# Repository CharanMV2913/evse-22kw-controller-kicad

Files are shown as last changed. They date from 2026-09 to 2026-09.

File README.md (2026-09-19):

# 22 kW EVSE controller project

The repository now contains the prototype implementation specification, safety-state-machine guidance, release checklist, and initial KiCad board outline.

This is an engineering prototype baseline, not a certified charger. The next mandatory step is exact component selection and schematic capture against the chosen external Type A + RDC-DD or Type B protection assembly. The board must remain SELV/control-only; do not add 415 V conductors to it.

See `docs/implementation-spec.md` and `docs/release-checklist.md` before ordering boards.

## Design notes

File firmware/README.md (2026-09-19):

# Prototype safety firmware skeleton

This folder contains only a safe-state reference skeleton. It does not control a certified EVSE by itself and must not be used as the sole contactor safety mechanism.

The firmware must default `CONTACTOR_REQUEST` low, require all local safety inputs healthy, and latch faults. The external normally-closed safety chain must interrupt the contactor coil independently of the ESP32-S3.

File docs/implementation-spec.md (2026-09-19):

# Prototype implementation specification

This document is the release baseline for schematic capture and assembly of the control PCB. It intentionally excludes the hazardous 415 V power path.

## Functional sections

### A. 24 V SELV input

`J1-1 = +24V_SELv`, `J1-2 = 0V_SELv`. Provide an input fuse/PTC, reverse-polarity protection, TVS, and buck/LDO rails for 12 V and 3.3 V. The selected supply must be certified and current-limited.

### B. ESP32-S3

Use an ESP32-S3-WROOM-1 module with the manufacturer's recommended decoupling, boot strapping, USB/UART programming interface, antenna keepout, and exposed-ground requirements. Do not route copper or place metal under the antenna keepout.

### C. Hardware safety interlock

The external safety chain provides an isolated `SAFETY_OK` status and independently interrupts the external contactor coil circuit. The PCB's `CONTACTOR_REQUEST` is only an enable request. The request path must default low during reset and be ANDed with a hardware watchdog/fault signal before reaching the external relay interface.

Inputs are active-low normally-closed safety contacts unless the selected certified module specifies otherwise:

- emergency stop
- RCD/RDC-DD trip
- PE monitor healthy
- phase/voltage monitor healthy
- thermal monitor healthy
- enclosure/door interlock

### D. Control Pilot / Proximity Pilot

Use a dedicated IEC 61851-compatible CP front end or a verified reference circuit. CP must provide state measurement, diode check, pilot duty-cycle measurement, and protected ±12 V pilot drive. PP is measured through a protected divider and must not be connected directly to an ESP32 pin. Final resistor values depend on the selected Type 2 inlet/socket and cable ratings.

### E. External module interfaces

All field/status inputs are isolated dry-contact or isolated digital interfaces. Provide current limiting, surge suppression, pull-up selection, and a defined inactive state. RS-485 requires an isolated transceiver, termination selection, bias selection, and shield/chassis treatment defined by the enclosure design.

## Required net names

`+24V_SELV`, `+12V_SELV`, `+3V3`, `0V_SELV`, `CP_IN`, `CP_DRIVE`, `PP_SENSE`, `CONTACTOR_REQUEST`, `SAFETY_OK`, `RCD_STATUS`, `RDC_DD_STATUS`, `E_STOP_STATUS`, `PE_MONITOR_STATUS`, `PHASE_MONITOR_STATUS`, `OVERTEMP_1`, `OVERTEMP_2`, `CONTACTOR_AUX_1`, `CONTACTOR_AUX_2`, `RS485_A`, `RS485_B`, `USB_D+`, `USB_D-`, `JTAG`, and `RESET_N`.

## Design constraints

- Four-layer board: signal / ground / power / signal.
- Keep field connectors at the board edge and separate from USB/RF.
- No mains nets, mains terminals, or mains-referenced components on the PCB.
- Maintain the isolation distances specified by each isolator and the applicable insulation coordination review.
- Add test points for every supply rail, CP, PP, safety status, reset, and contactor request.
- Add a clearly marked programming/service connector that cannot be mistaken for a field connector.

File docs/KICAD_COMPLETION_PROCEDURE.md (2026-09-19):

# KiCad completion procedure

This procedure is required before the project can be considered complete.

## 1. Start from a clean KiCad project

Open the project in the target KiCad version and replace any placeholder or malformed library entries using the official KiCad libraries and vendor-provided footprints.

## 2. Capture the schematic

Create these hierarchical sheets:

- `power_se_lv`: protected 24 V input, fuse/PTC, reverse-polarity protection, regulator rails, supervisor;
- `esp32s3`: exact module, reset/boot, USB/JTAG and decoupling;
- `safety_interlock`: isolated status contacts and hardware request inhibit;
- `cp_pp`: selected IEC 61851 CP/PP reference circuit;
- `contactor_io`: external 24 V relay/contactor interface and auxiliary feedback;
- `rs485_service`: isolated meter interface and service connector.

Every external input needs a defined inactive state, transient protection, and a documented isolation boundary. Every connector must have a pinout table and mating-part reference.

## 3. Validate

Run annotation, electrical rules check, footprint assignment, and design review. Do not suppress errors merely to obtain a clean report; document every intentional exception.

## 4. Place and route

Use the selected manufacturer's recommended land patterns. Keep the RF antenna area clear. Separate field interfaces, CP/PP, switching outputs, USB, and RF. Apply the required creepage and clearance based on the actual isolation ratings and enclosure.

## 5. Release

Run PCB design rules, inspect the 3D board, generate the BOM and pick-and-place files, and have an independent engineer review the power and safety interface. Do not generate or use mains fabrication outputs until this review is complete.

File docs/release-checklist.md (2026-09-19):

# Schematic capture and assembly checklist

The current board outline is not fabrication-ready until all items below are completed and reviewed.

## Schematic

- [ ] Select exact ESP32-S3-WROOM-1 variant and validate boot pins.
- [ ] Select certified 24 V SELV supply and define current budget.
- [ ] Select CP front-end/reference design and validate IEC 61851 behavior.
- [ ] Define the exact RCD/RDC-DD and PE/phase monitor dry-contact behavior.
- [ ] Complete safety-chain hardware logic independent of firmware.
- [ ] Add watchdog supervisor and reset behavior.
- [ ] Add reverse-polarity, overcurrent, and transient protection to external interfaces.
- [ ] Add connector pinout, keying, labels, and shield/chassis strategy.
- [ ] Annotate every component and assign exact footprints.
- [ ] Run ERC with intentional exceptions documented.

## PCB

- [ ] Place antenna keepout and USB connector first.
- [ ] Place isolation components as a physical boundary.
- [ ] Route clocks/USB/RF per vendor guidance.
- [ ] Route CP/PP away from noisy switching and RS-485.
- [ ] Add mounting holes and enclosure datum references.
- [ ] Add test points and production labels.
- [ ] Run DRC with manufacturer rules.
- [ ] Generate 3D and assembly review.

## Verification

- [ ] Test with a current-limited SELV bench supply only.
- [ ] Verify boot-fail and watchdog-fail contactor shutdown.
- [ ] Verify every safety input causes a latched non-energized state.
- [ ] Verify welded-contactor detection using a simulator.
- [ ] Verify CP/PP state machine with a certified EVSE test instrument.
- [ ] Verify isolation and dielectric withstand through a qualified lab.
- [ ] Complete thermal, EMC, enclosure, RCD and installation validation before mains use.

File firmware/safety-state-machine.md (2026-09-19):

# EVSE firmware safety state machine

This is implementation guidance for the ESP32-S3 prototype. It is not a safety certification or a substitute for the hardwired interlock.

```text
BOOT
  -> SELF_TEST
  -> FAULT_LATCHED       if watchdog, brownout, invalid hardware, or unsafe input
  -> IDLE                if every safety input is healthy

IDLE
  -> CONNECTED           when PP indicates a valid cable/vehicle presence
  -> FAULT_LATCHED       if any safety input is unhealthy

CONNECTED
  -> READY                when CP state is valid and vehicle requests charging
  -> IDLE                 when cable is removed
  -> FAULT_LATCHED        on CP diode/state failure or safety fault

READY
  -> CHARGING             only after hardware safety chain is healthy and contactor feedback is open
  -> IDLE                 when vehicle releases request
  -> FAULT_LATCHED        on timeout or safety fault

CHARGING
  -> STOPPING             on vehicle release, timeout, communication loss, or any safety fault

STOPPING
  -> IDLE                 only after contactor auxiliary confirms open
  -> FAULT_LATCHED        if contactor remains closed or timeout expires

FAULT_LATCHED
  -> IDLE                 only after the external safety condition is restored and a deliberate reset is accepted
```

The firmware must use a monotonic timeout source, feed the watchdog only while the state machine is healthy, and drive `CONTACTOR_REQUEST` low before attempting recovery. A cloud/UI command must never bypass the local safety checks.

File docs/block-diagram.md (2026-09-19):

# System block diagram

```text
  415 V 3-phase supply
          |
  [External certified power assembly]
  isolator | MCB/fuses | SPD | RCD/RCM
          |
     4-pole contactor -------------------- Type 2 socket
          |                                      |
          +-- auxiliary contacts                 +-- CP / PP

  [Control PCB: SELV only]
  ESP32-S3 -> CP/PP interface -> Type 2 connector
      |
      +-> enable request -> hardware safety interlock -> external contactor coil driver
      |
      +<- isolated feedback: RCD/RDC-DD, PE monitor, phase monitor,
      |   emergency stop, overtemperature, contactor auxiliary contacts
      |
      +-> optional isolated RS-485 energy meter / service communications
```

## Hardwired shutdown

The ESP32-S3 may request charging, but it must not be the sole safety shutdown path. The external contactor coil-enable circuit must be interrupted by the normally-closed safety chain, including emergency stop, RCD/RDC-DD trip, PE fault, overtemperature, and phase/voltage fault. The controller should observe the resulting isolated status contacts and enter a latched fault state.

## Isolation boundary

No 415 V conductor is routed on this board. Field inputs must be SELV or galvanically isolated dry contacts. CP/PP circuitry must be designed for the selected Type 2 socket and protected against connector transients.

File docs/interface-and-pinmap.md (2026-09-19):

# Interfaces and proposed ESP32-S3 pin map

This mapping is a starting point for an ESP32-S3-WROOM-1 prototype and must be checked against the selected module's strapping, USB/JTAG, flash, PSRAM, and boot requirements.

| GPIO | Function | Direction | Notes |
|---:|---|---|---|
| 4 | CP_ADC | input | Pilot-state measurement |
| 5 | CP_STATE | input | Comparator/state indication |
| 6 | PP_ADC | input | Protected proximity measurement |
| 7 | CONTACTOR_REQUEST | output | Request only; not the safety chain |
| 8 | CONTACTOR_AUX_1 | input | Isolated auxiliary contact |
| 9 | CONTACTOR_AUX_2 | input | Optional second auxiliary contact |
| 10 | RCD_STATUS | input | Isolated dry contact |
| 11 | RDC_DD_STATUS | input | Isolated dry contact, if used |
| 12 | E_STOP_STATUS | input | Normally-closed loop status |
| 13 | PE_MONITOR_STATUS | input | External monitor status |
| 14 | PHASE_MONITOR_STATUS | input | External relay status |
| 15 | OVERTEMP_1 | input | Socket/terminal sensor module |
| 16 | OVERTEMP_2 | input | Contactor/enclosure sensor module |
| 17 | RS485_DE_RE | output | Isolated transceiver direction |
| 18 | RS485_RX | input | Isolated Modbus meter |
| 19 | RS485_TX | output | Isolated Modbus meter |
| 20 | STATUS_GREEN | output | Status LED |
| 21 | STATUS_RED | output | Fault LED |
| 22 | SERVICE_INPUT | input | Local service/control input |
| 23 | HARDWARE_FAULT_STATUS | input | Safety-chain monitor |

## External connectors

- `J1`: 24 V SELV power input from protected external supply
- `J2`: external contactor enable/coil-interface module
- `J3`: isolated safety-status inputs
- `J4`: Type 2 CP/PP interface
- `J5`: isolated RS-485
- `J6`: service/debug header

Connector pinout and mating parts must be frozen before schematic release. Use keyed, touch-safe connectors and strain relief appropriate for the enclosure.

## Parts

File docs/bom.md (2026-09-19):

# BOM and selection requirements

This is a selection checklist, not a release BOM. Exact manufacturer part numbers require the final schematic, enclosure, supply, and certification strategy.

| Reference/category | Requirement |
|---|---|
| U1 | ESP32-S3-WROOM-1 or approved equivalent; module antenna keepout respected |
| U2 | Isolated RS-485 transceiver if an external meter is used |
| U3 | Hardware watchdog/supervisor with reset output |
| U4 | CP front-end designed for IEC 61851 pilot levels and protected from transients |
| U5 | Isolated DC/DC or certified SELV supply interface as required by system architecture |
| K1 | External 24 V contactor/relay safety interface; suitably rated and certified |
| F1 | Local low-voltage input protection, sized for the selected supply |
| TVS parts | Rated for each external interface and its fault/transient environment |
| Optocouplers/digital isolators | Safety/status inputs with required isolation voltage and creepage |
| J1-J6 | Touch-safe, keyed, locking connectors with appropriate ratings |
| Sensors | External RCD/RDC-DD, PE monitor, phase monitor, and thermal devices with isolated status outputs |

The Type A + 6 mA RDC-DD and Type B RCD are alternative protection architectures. Select one certified external assembly and document its trip contact behavior, reset behavior, leakage limits, and coordination with the upstream installation.

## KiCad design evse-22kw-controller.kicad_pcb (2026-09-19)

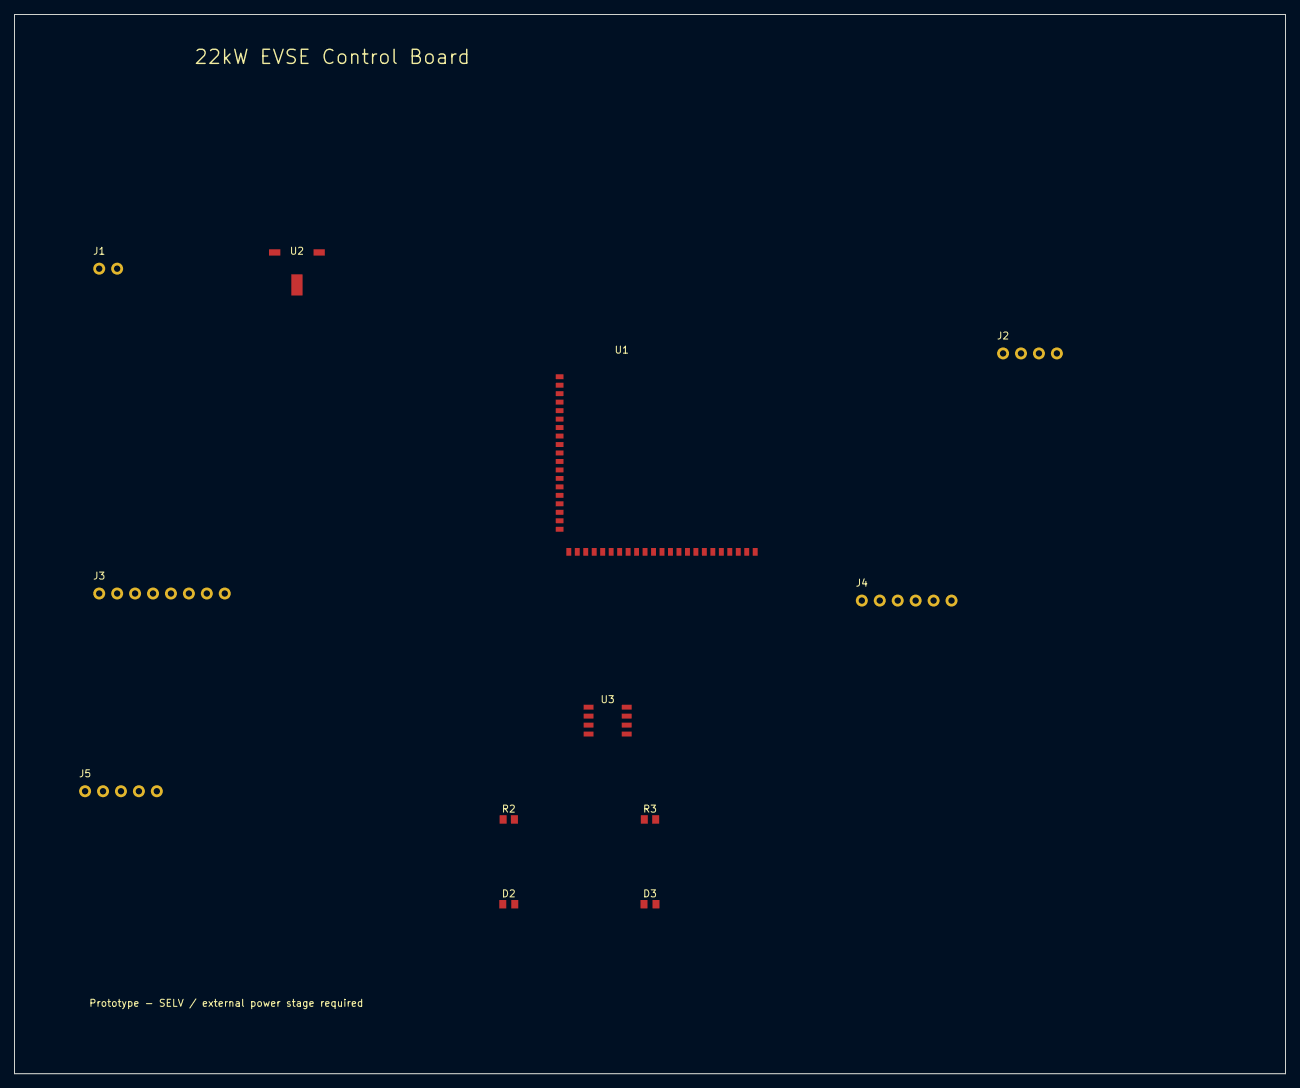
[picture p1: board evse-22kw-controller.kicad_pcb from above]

Board: 2 copper layers, 180.0 x 150.0 mm, 12 parts (0 on the bottom side), 8 nets, no tracks yet.

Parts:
D2, D3: LED_0603_1608Metric
J1: Molex_KK-254_AE-6410-02A_1x02_P2.54mm_Vertical
J2: Molex_KK-254_AE-6410-04A_1x04_P2.54mm_Vertical
J3: Molex_KK-254_AE-6410-08A_1x08_P2.54mm_Vertical
J4: Molex_KK-254_AE-6410-06A_1x06_P2.54mm_Vertical
J5: Molex_KK-254_AE-6410-05A_1x05_P2.54mm_Vertical
R2, R3: R_0603_1608Metric
U1: ESP32-S3-WROOM-1
U2: SOT-223-3_TabPin2
U3: SOIC-8_3.9x4.9mm_P1.27mm

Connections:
0V_SELV: D2.1, D3.1, J1.2, J2.4, J3.8, J4.3, J4.4, J4.5, J4.6, J5.5, R2.2, R3.2, U1.1, U1.9, U1.10, U1.11, U1.12, U1.13, U1.14, U1.15, U1.16, U1.17, U1.18, U1.19, U1.20, U1.21, U1.22, U1.24, U1.25, U1.26, U1.27, U1.28, U1.29, U1.30, U1.31, U1.32, U1.33, U1.34, U1.35, U1.36, U1.37, U1.38, U1.39, U1.40, U1.41, U1.42, U2.1, U3.1, U3.2, U3.3, U3.5, U3.6, U3.7
+3V3: D2.2, D3.2, R2.1, R3.1, U1.2, U1.23, U2.2, U3.8
+24V_SELV: J1.1, J2.1, U2.3
GPIO4: J5.3, U1.4, U3.4
GPIO5: J5.4, U1.5
GPIO7: U1.7, U1.8
RCD_STATUS: J3.1, J3.2
SAFETY_OK: J2.3, J3.4, J3.5, J3.6, J3.7, U1.3

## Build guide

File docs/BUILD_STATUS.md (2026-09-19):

# Build status — not fabrication-ready

## Current status

This repository contains a **conceptual prototype baseline only**. It must not be used to order or assemble a mains-connected EVSE.

The files named `evse-22kw-controller.kicad_sch` and `evse-22kw-controller.kicad_pcb` have not been validated by KiCad ERC/DRC in this repository. They are not evidence of a complete, electrically correct schematic or routed PCB.

## Blocking items

1. Exact ESP32-S3 module variant and manufacturer footprint must be selected and checked against the vendor datasheet.
2. A certified IEC 61851 CP/PP front-end must be selected; CP/PP cannot be safely finalized from placeholder symbols.
3. The external 24 V contactor/relay interface and its coil-current/fault behavior must be specified.
4. The Type A + RDC-DD or Type B RCD architecture must be selected; both are not automatically interchangeable.
5. All field connectors, isolation requirements, protection, and enclosure interfaces must be frozen.
6. A valid KiCad schematic must be captured using installed KiCad libraries, then annotated and checked with ERC.
7. The PCB must be updated from the checked schematic, fully routed, and checked with DRC and manufacturer rules.
8. CP/PP behavior, safety-chain behavior, insulation, EMC, thermal performance, and RCD operation require qualified testing.

## Safe completion criterion

The project may only be called complete when a qualified engineer has reviewed the design and the following artifacts exist:

- valid KiCad schematic with no unexplained ERC errors;
- PCB updated from that schematic with no unexplained DRC errors;
- locked footprints and manufacturer part numbers;
- assembly drawings, BOM, and fabrication outputs;
- verified external power/safety assembly;
- documented test results for the applicable Indian and IEC requirements.

Until then, keep the board disconnected from 415 V and use only current-limited SELV bench testing.

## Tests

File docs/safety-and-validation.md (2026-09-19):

# Safety and validation requirements

## Safety boundary

This prototype board is SELV/control electronics only. It is not a mains-rated PCB and does not replace an RCD, RDC-DD, protective device, contactor, isolator, PE monitor, or certified EVSE controller.

## Required external protection

- Main isolator and coordinated overcurrent protection
- Surge protection suitable for the installation
- Type A 30 mA plus certified 6 mA DC RDC-DD, or a Type B RCD
- 4-pole contactor where required by the installation/design
- Emergency-stop device and normally-closed safety loop
- PE continuity/earth monitoring appropriate to the selected EVSE architecture
- Phase sequence/loss and voltage monitoring
- Thermal monitoring of socket/terminals/contactor where required

## Firmware safety rules

1. Boot into a non-energized state.
2. Require all safety inputs healthy before a contactor request.
3. Never infer safety from Wi-Fi, cloud, or user-interface state.
4. Remove the request on watchdog reset, brownout, invalid CP state, or communication failure.
5. Latch faults until a deliberate, safe reset procedure is completed.
6. Verify contactor auxiliary feedback after every transition and detect welded contacts.

## Validation before any mains connection

- Visual inspection and polarity/continuity checks
- Protective-earth continuity and bonding verification
- SELV-to-field isolation and insulation-resistance testing
- Dielectric withstand testing by a qualified laboratory/engineer
- Emergency-stop and hardwired safety-chain interruption tests
- RCD/RDC-DD trip and reset tests using calibrated equipment
- Contactor weld and auxiliary-feedback tests
- CP/PP conformance and state-transition tests
- Thermal and enclosure ingress validation
- EMC and functional testing under representative load
- Review against applicable Indian requirements, IS 17017 series, IEC 61851, IEC 62955, and local electrical rules

Do not use this repository as evidence that the resulting assembly is certified or safe for public or unattended operation.

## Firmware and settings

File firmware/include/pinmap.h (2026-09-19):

#pragma once

// Prototype GPIO map. Verify against the exact ESP32-S3 module and boot configuration.
#define PIN_CP_ADC              4
#define PIN_CP_STATE            5
#define PIN_PP_ADC              6
#define PIN_CONTACTOR_REQUEST   7
#define PIN_CONTACTOR_AUX_1     8
#define PIN_CONTACTOR_AUX_2     9
#define PIN_RCD_STATUS         10
#define PIN_RDC_DD_STATUS      11
#define PIN_ESTOP_STATUS       12
#define PIN_PE_MONITOR_STATUS  13
#define PIN_PHASE_MONITOR      14
#define PIN_OVERTEMP_1         15
#define PIN_OVERTEMP_2         16
#define PIN_RS485_DE_RE        17
#define PIN_RS485_RX           18
#define PIN_RS485_TX           19
#define PIN_STATUS_GREEN       20
#define PIN_STATUS_RED         21
#define PIN_SERVICE_INPUT      22
#define PIN_HARDWARE_FAULT     23

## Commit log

2026-09-19 Add initial KiCad EVSE controller project skeleton and safety documentation
    [evse-22kw-controller.kicad_pcb]
2026-09-19 Complete prototype implementation specification, safety state machine, and release checklist
2026-09-19 Create a prototype KiCad schematic and PCB baseline for the EVSE controller control board.
    [evse-22kw-controller.kicad_pcb, evse-22kw-controller.kicad_sch]
2026-09-19 Add completion procedure, explicit build status, and safe prototype firmware skeleton
